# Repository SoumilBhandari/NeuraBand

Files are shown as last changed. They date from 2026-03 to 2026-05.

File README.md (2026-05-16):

<div align="center">

<h1>NeuraBand</h1>

<p><b>A wearable biomarker monitor built to help slow the progression of Alzheimer's disease</b></p>

<p>
NeuraBand is a pill-sized wearable that continuously and passively tracks <b>ten</b> neurologically
relevant biomarkers, then streams them live over Bluetooth Low Energy to a clinical-grade
dashboard and a patient-facing mobile app. Its purpose is not simply to detect Alzheimer's
disease — it is to <b>slow the disease's progression</b>, by surfacing the earliest warning signs
while there is still time for intervention to change its course.
</p>

<p>






</p>

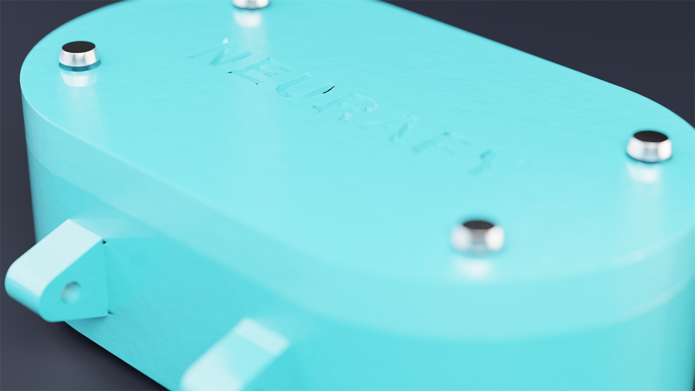
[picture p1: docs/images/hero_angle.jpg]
NeuraBand wearable device — angled render


</div>

---

<p align="center">
<a href="#why-it-matters">Why It Matters</a> &nbsp;·&nbsp;
<a href="#how-it-works">How It Works</a> &nbsp;·&nbsp;
<a href="#the-ten-modalities">Modalities</a> &nbsp;·&nbsp;
<a href="#the-device">The Device</a> &nbsp;·&nbsp;
<a href="#whats-in-this-repo">Components</a> &nbsp;·&nbsp;
<a href="#quick-start">Quick Start</a> &nbsp;·&nbsp;
<a href="#bill-of-materials">BOM</a> &nbsp;·&nbsp;
<a href="#ble-protocol">BLE Protocol</a> &nbsp;·&nbsp;
<a href="#scientific-basis">Science</a>
</p>

---

## Why It Matters

Alzheimer's disease begins damaging the brain **years before memory symptoms appear** — and
some of the earliest regions affected are those that govern *autonomic* functions: heart-rhythm
regulation, skin conductance, and motor coordination. Today those changes are usually caught
only at an annual clinic visit, if at all.

NeuraBand takes the opposite approach: **continuous, passive monitoring**. By wearing one
unobtrusive band, a subject contributes a 24/7 stream of prodromal biomarkers — the kind of
longitudinal signal that periodic assessments simply cannot capture.

Detection, though, is only the first step. The early window NeuraBand opens is also the
**treatable** window — the sooner decline is caught, the sooner lifestyle changes, medication,
and clinical care can begin. Earlier, better-informed intervention is what gives a person the
best chance of **slowing how fast Alzheimer's progresses**, and that is the outcome NeuraBand
is built for.

Four of the ten tracked modalities are *primary* AD biomarkers, each chosen for a documented
link to neurodegeneration:

| Biomarker | Sensor | Why it is relevant to Alzheimer's |
|---|---|---|
| **Heart-rate variability** | MAX30102 PPG | Low HRV reflects autonomic dysfunction; the lowest-HRV / highest blood-pressure-variability quartile carries a **2.34× ADRD risk** *(Rouch et al., 2024)*. |
| **Blood oxygen (SpO₂)** | MAX30102 pulse oximetry | Reduced peripheral SpO₂ is associated with cognitive impairment and sleep-disordered breathing. |
| **Electrodermal activity** | Grove GSR + built-in electrodes | EDA is governed by the ventromedial frontal cortex and anterior cingulate — regions hit early in AD pathology. |
| **Gait variability** | BMI270 IMU | The **strongest evidence base**: wearable-IMU gait analysis differentiates dementia subtypes, and ML on gait data reaches **85.5% accuracy** detecting mild cognitive impairment. |

> No single biomarker is diagnostic. NeuraBand's value is in **fusing many weak signals** into one
> longitudinal picture — see the [Scientific Basis](#scientific-basis) section for 13
> peer-reviewed studies behind these choices.

---

## How It Works

Six sensors feed an Arduino Nano 33 BLE Sense Rev2. On-device firmware fuses them into ten
modality streams plus a composite **Neuro-Risk Index**, packages everything as a compact JSON
frame once per second, and notifies any connected Bluetooth client.

```
   SENSORS                         DEVICE                              CLIENTS

 MAX30102  --+                                                  +-->  Web Dashboard
 Grove GSR --+                                                  |     Web Bluetooth / Chrome
 BMI270    --+--> Arduino Nano 33 BLE Sense Rev2  --BLE 5.0 -----+
 HS3003    --+      nRF52840 SoC                                 |
 APDS9960  --+      10-modality fusion + Neuro-Risk Index        +-->  Mobile App
 LPS22HB   --+      JSON telemetry @ 1 Hz                              React Native / Expo
```

The device exposes one custom 128-bit GATT service over Bluetooth Low Energy. Any Web Bluetooth
browser or the React Native app can connect to it directly — no pairing dance, no cloud account,
no companion dongle.

---

## The Ten Modalities

The Nano 33 BLE Sense carries an IMU and environmental sensors on-board, so a single external
PPG breakout and a GSR module are enough to surface **ten** continuous streams:

| # | Modality | Sensor | What it captures |
|:-:|---|---|---|
| 1 | Heart-rate variability | MAX30102 PPG | SDNN / RMSSD / IBI — autonomic regulation |
| 2 | Blood oxygen (SpO₂) | MAX30102 | Peripheral oxygenation |
| 3 | Electrodermal activity | Grove GSR + SS electrodes | Sympathetic / stress response |
| 4 | Gait variability | BMI270 IMU | Activity level and motor patterns |
| 5 | Respiratory rate | MAX30102 (PPG envelope) | Breathing extracted from sinus arrhythmia |
| 6 | Skin temperature | HS3003 | Circadian-rhythm tracking |
| 7 | Sleep quality | BMI270 actigraphy | Cole–Kripke sleep/wake estimation |
| 8 | Skin humidity | HS3003 | Sweat / sympathetic response |
| 9 | Ambient light | APDS9960 | Circadian light exposure |
| 10 | Barometric pressure | LPS22HB | Altitude / floor-change detection |
| ★ | **Neuro-Risk Index** | *computed* | Weighted fusion of every stream into a 0–100 score |

---

## The Device

A 70 × 42 × 21 mm pill-shaped enclosure, 3D-printed in PLA, that mounts to any standard 24 mm
quick-release watch band. The skin-facing surface integrates the optical PPG window and two
stainless-steel GSR electrodes; the side carries a USB-C charging port and a power switch.

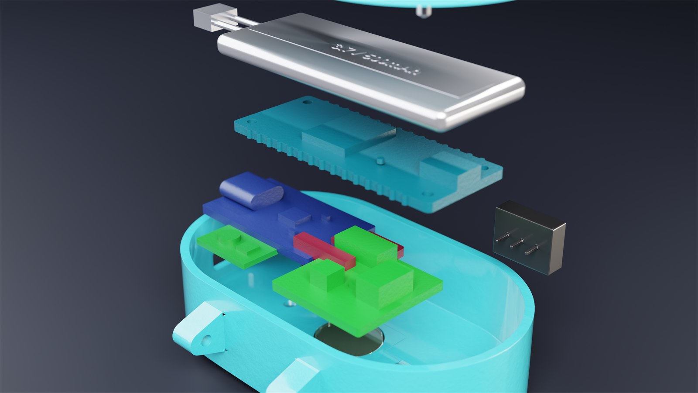
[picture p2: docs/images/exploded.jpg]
Exploded view of the NeuraBand assembly


<table>
<tr>
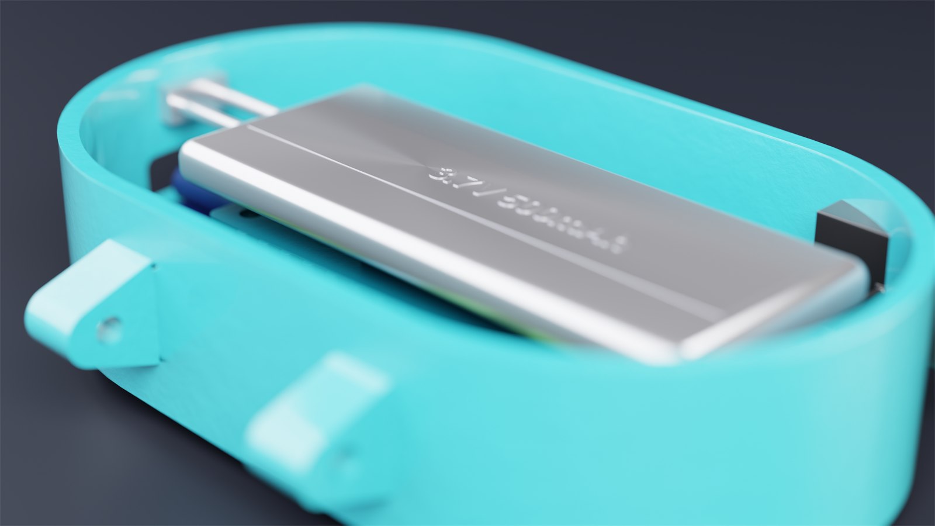
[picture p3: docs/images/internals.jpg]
Internal layout
<td width="50%"></td>
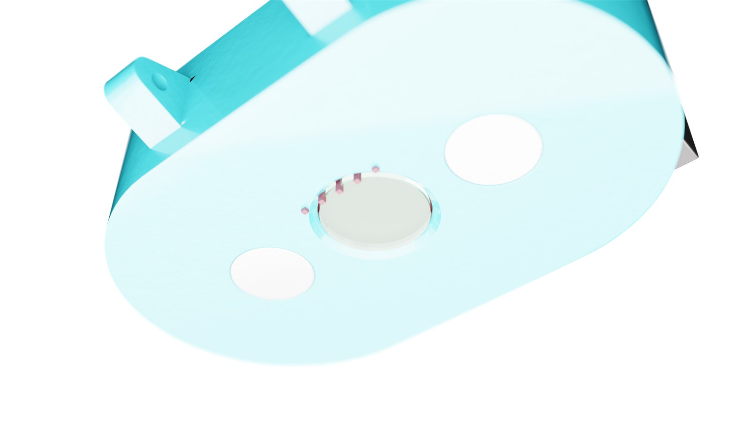
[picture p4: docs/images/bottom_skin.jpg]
Skin-contact surface with PPG window and electrodes
<td width="50%"></td>
</tr>
<tr>
<td align="center"><sub>500 mAh LiPo seated above the Arduino</sub></td>
<td align="center"><sub>Skin side — optical PPG window flanked by GSR electrodes</sub></td>
</tr>
<tr>
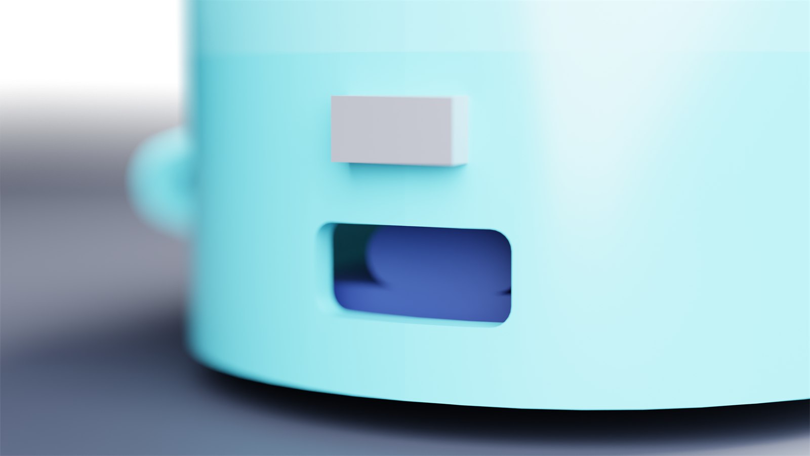
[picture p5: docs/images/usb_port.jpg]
USB-C charging port
<td width="50%"></td>
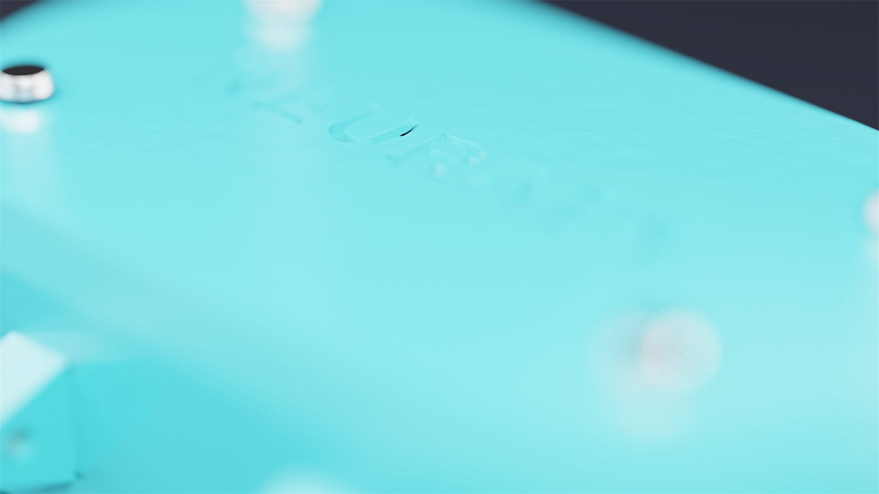
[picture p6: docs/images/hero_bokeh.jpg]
Enclosure detail
<td width="50%"></td>
</tr>
<tr>
<td align="center"><sub>USB-C charge port and power switch</sub></td>
<td align="center"><sub>Embossed shell — print-finished detail</sub></td>
</tr>
</table>

---

## What's in This Repo

NeuraBand is a full hardware-plus-software build. Every layer lives here:

### Firmware &nbsp;·&nbsp; `firmware/`

An 884-line Arduino sketch (`neuraband_firmware.ino`) that runs the whole device:

- **10-modality sensor fusion** with non-blocking `millis()` scheduling — MAX30102 at 50 Hz,
  GSR and IMU at 10 Hz, environmental sensors at 0.1 Hz, BLE transmit at 1 Hz.
- **On-device HRV** — SDNN computed from a rolling 60-sample inter-beat-interval buffer.
- **SpO₂** via a ratio-of-ratios method with an empirical MAX30102 calibration curve.
- **Respiratory rate** extracted from the PPG amplitude envelope (respiratory sinus arrhythmia).
- **Sleep actigraphy** — a simplified Cole–Kripke classifier over a 5-minute motion window.
- **Composite Neuro-Risk Index** — weighted multimodal fusion into a single 0–100 score.
- **Resilience built in** — software watchdog (resets on a >5 s loop stall), I²C bus
  auto-recovery, a BLE software-reset characteristic, and tri-color LED status indicators.

### Clinical Dashboard &nbsp;·&nbsp; `dashboard/`

A zero-install web app that connects straight to the device through the **Web Bluetooth API**.

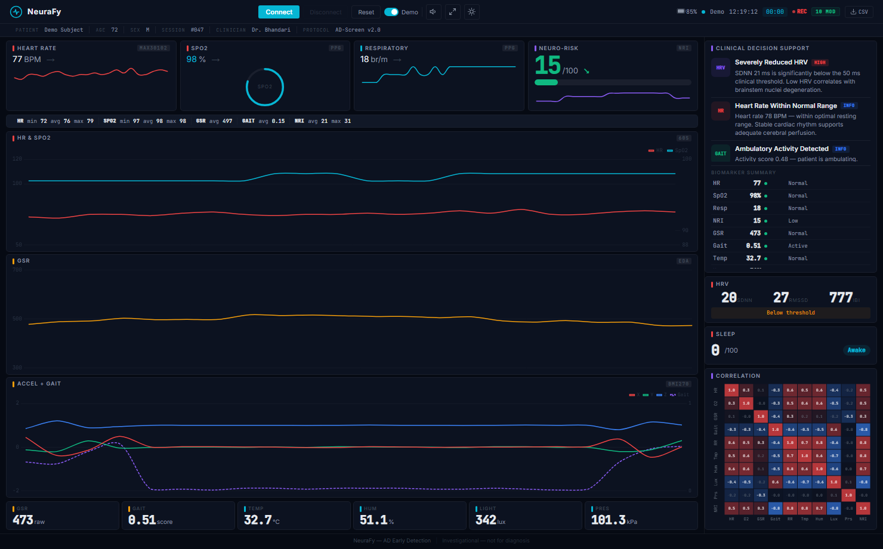
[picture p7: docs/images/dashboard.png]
NeuraBand clinical dashboard in demo mode


- Real-time Chart.js plots (HR & SpO₂, GSR, accelerometer + gait) on a 60-second rolling window.
- A **Clinical Decision Support** panel that turns evidence-based thresholds into plain-language
  insights, alongside a 10-modality biomarker summary table.
- Dedicated HRV (SDNN / RMSSD / IBI), SpO₂ ring, sleep, and cross-modality correlation panels.
- Dark / light themes, a session timer, CSV export for ML pipelines, auto-reconnect, and a
  **demo mode** that streams synthetic physiology so the dashboard works with no hardware.
- Ships as `index.html` + `app.js` + `style.css`, plus a single-file `neurafy_standalone.html`.

### Mobile App &nbsp;·&nbsp; `mobile/`

A patient-facing React Native companion (Expo SDK 54, React Native 0.81) — the friendly
counterpart to the clinician dashboard.

- Five tabs — **Vitals**, **Trends**, **Tips**, **Ask**, and **More** — behind a guided
  onboarding flow.
- Connects to the band over BLE with `react-native-ble-plx`; clinical terms are softened into
  everyday language (*Brain Health*, *Heart Calmness*, *Movement*).
- A daily wellness score, a wear-streak tracker, and a conversational **health assistant** that
  answers plain-language questions about the latest readings.
- System-driven dark / light theming, haptics, on-device persistence, and the same synthetic
  **demo mode** — the app is fully explorable without a physical device.

### Enclosure &nbsp;·&nbsp; `enclosure/`

- A fully **parametric OpenSCAD** model (`neuraband_case.scad`) — every component pocket,
  the optical window, electrode bores, lug tabs, and screw bosses are driven by named variables.
- Ready-to-print STL shells (`bottom_shell.stl`, `top_shell.stl`, `test_fit.stl`) plus a `stl/`
  library of component models for fit visualization.
- High-resolution product renders (`renders/`) generated by the included Blender script
  `render_neurafy.py`.

### Docs &nbsp;·&nbsp; `docs/`

The full [bill of materials](docs/bom.md), a [wiring diagram](docs/wiring_diagram.txt) with the
complete pin map and I²C address table, [13 scientific references](docs/scientific_references.md),
and a printable parts-list PDF.

---

## Quick Start

Every part of NeuraBand can be explored on its own — and the dashboard and app both have a demo
mode, so **you do not need to build the hardware to try the software**.

### 1 · Print the enclosure

Open the print-ready wrappers in OpenSCAD, or drop the STL files straight into your slicer.

| Setting | Value |
|---|---|
| Layer height | 0.15 mm |
| Walls | 4 perimeters |
| Infill | 40% gyroid |
| Material | PLA (210 °C / 60 °C) |
| Supports | Tree — lug tabs only |
| Brim | 5 mm |

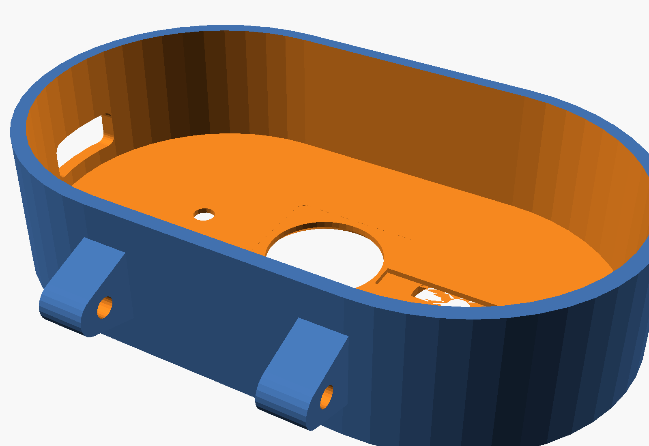
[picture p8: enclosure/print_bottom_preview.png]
Sliced bottom shell preview


### 2 · Flash the firmware

```bash
# Arduino IDE 2.x — install these from the Library Manager:
#   ArduinoBLE · Arduino_BMI270_BMM150 · Arduino_HS300x
#   Arduino_APDS9960 · Arduino_LPS22HB · SparkFun MAX3010x Sensor Library

# Board:  Arduino Nano 33 BLE
# Sketch: firmware/neuraband_firmware/neuraband_firmware.ino
# Connect the board over USB and upload (Ctrl/Cmd + U)
```

### 3 · Launch the dashboard

```bash
cd dashboard
python -m http.server 8000
# Open Chrome at http://localhost:8000
# Click "Connect" and pick "NeuraFy" (the device's Bluetooth name) — or flip "Demo" for no hardware.
```

> Web Bluetooth requires Chrome, Edge, or another Chromium browser over `http://localhost` or HTTPS.

### 4 · Run the mobile app

```bash
cd mobile
npm install
npx expo start
# Scan the QR code with Expo Go, or press  i / a  for an iOS / Android simulator.
```

The app opens in demo mode out of the box — no device or pairing required.

---

## Bill of Materials

The core electronics come in around **$55–65**; a complete build with band, fasteners, and
filament lands near **$75–85**.

| Component | Qty | Approx. cost | Notes |
|---|:---:|:---:|---|
| Arduino Nano 33 BLE Sense Rev2 | 1 | $35 | nRF52840, BMI270 IMU, BLE 5.0 |
| MAX30102 breakout (RCWL-0531) | 1 | $3–5 | Must be the 3.3 V I²C variant |
| Grove GSR sensor | 1 | $8–10 | Includes electrodes and cable |
| 500 mAh LiPo battery | 1 | $5–8 | Flat pouch with JST connector |
| TP4056 USB-C charging module | 1 | $2–3 | DW01A-protected (6-pin) version |
| MT3608 boost converter | 1 | $1–2 | Adjusted to 5.0 V output |
| Quick-release watch band (24 mm) | 1 | ~$5 | Standard spring-bar band |
| 3D-print filament, M2 screws, wiring, VHB tape | — | ~$10 | See full list |

> The complete, itemized list — including optional finishing supplies and required tools —
> is in [`docs/bom.md`](docs/bom.md).

---

## BLE Protocol

The device exposes one custom 128-bit GATT service. Sensor frames are pushed via notifications
once per second.

| Characteristic | UUID | Access | Purpose |
|---|---|---|---|
| Service | `19B10000-E8F2-537E-4F6C-D104768A1214` | — | GATT service container |
| Sensor Data | `19B10001-…` | Notify (1 Hz) | JSON sensor frame |
| Device Status | `19B10002-…` | Read | Firmware version + per-sensor health |
| Reset Command | `19B10003-…` | Write | Write `0x01` to reboot the device |

Each `Sensor Data` notification is a compact JSON object:

```json
{"hr":74,"sp":98,"gsr":487,"gait":0.42,"ibi":810,"ax":0.01,"ay":-0.99,"az":0.12,
 "rr":16,"tmp":32.4,"hum":48.0,"lux":220,"prs":101.3,"slp":82,"slps":0,"nri":21,
 "bt":85,"ts":42000}
```

| Key | Field | Key | Field |
|-----|---|-----|---|
| `hr` | Heart rate (BPM) | `tmp` | Skin temperature (°C) |
| `sp` | SpO₂ (%) | `hum` | Skin humidity (%) |
| `gsr` | Electrodermal activity (raw ADC) | `lux` | Ambient light (clear channel) |
| `gait` | Gait activity score | `prs` | Barometric pressure (kPa) |
| `ibi` | Inter-beat interval (ms) | `slp` | Sleep quality score (0–100) |
| `ax` `ay` `az` | Accelerometer (g) | `slps` | Sleeping flag (0 / 1) |
| `rr` | Respiratory rate (breaths/min) | `nri` | Neuro-Risk Index (0–100) |
| `bt` | Battery (%, −1 if unmonitored) | `ts` | Uptime (ms since boot) |

---

## Repository Layout

```
NeuraBand/
├── firmware/
│   └── neuraband_firmware/
│       └── neuraband_firmware.ino     Arduino firmware (884 lines)
├── dashboard/
│   ├── index.html · app.js · style.css   Web Bluetooth clinical dashboard
│   └── neurafy_standalone.html         Single-file build (no server needed)
├── mobile/
│   ├── App.js                          Entry point + tab navigation
│   └── src/
│       ├── screens/                    Vitals · Trends · Tips · Ask · Settings · Onboarding
│       ├── components/                 Reusable UI building blocks
│       ├── context/ · services/        BLE + synthetic-demo data providers
│       └── utils/                      HRV, threshold, and trend helpers
├── enclosure/
│   ├── neuraband_case.scad             Parametric OpenSCAD source
│   ├── print_*.scad · *.stl            Print-ready parts
│   ├── stl/ · renders/                 Component models + product renders
│   └── render_neurafy.py               Blender render script
├── docs/
│   ├── bom.md · wiring_diagram.txt     Build references
│   ├── scientific_references.md        13 peer-reviewed citations
│   └── images/                         README assets
└── README.md
```

---

## Scientific Basis

Each primary biomarker was selected from the peer-reviewed literature. Gait carries the
strongest evidence; HRV, SpO₂, and EDA are supporting signals whose power comes from being
combined rather than read in isolation.

<details>
<summary><b>13 peer-reviewed studies — click to expand</b></summary>

<br>

**Heart-rate variability**
1. da Silva VP et al. *Heart Rate Variability Indexes in Dementia: A Systematic Review.* Curr Alzheimer Res. 2018.
2. Choe YM et al. *HRV response to physical challenge predicts cognitive decline in MCI.* Front Aging Neurosci. 2022.
3. Rouch L et al. *Combined blood-pressure variability and HRV predict ADRD risk (HR 2.34).* Sci Rep. 2024.
4. Eyre B et al. *A critical perspective on HRV as an AD biomarker.* J Alzheimers Dis. 2026.

**Blood oxygen (SpO₂)**
5. *Peripheral oxygen saturation and cognitive impairment.* Sci Rep. 2025.
6. Bhatt S et al. *Sleep-disordered breathing, oxygenation coupling, and cognitive decline.* Sci Rep. 2024.

**Electrodermal activity**
7. Tranel D, Damasio H. *Neuroanatomical correlates of electrodermal responses.* Psychophysiology. 1994.
8. Tranel D. *Electrodermal activity in cognitive neuroscience.* Oxford Handbook of ERP Components. 2011.
9. van den Berg ME et al. *Electrodermal activity in dementia assessment.* Dement Geriatr Cogn Disord Extra. 2018.

**Gait analysis** *(strongest evidence)*
10. Mc Ardle R et al. *Wearable accelerometers differentiate dementia subtypes.* Gait Posture. 2020.
11. Soltani A et al. *ML ensemble achieves 85.5% MCI detection from IMU gait data.* Front Neurol. 2024.
12. Mc Ardle R et al. *Multi-centre study of gait changes in mild AD.* Alzheimers Res Ther. 2020.
13. *Wearable sensor system for early AD detection via multilevel gait assessment.* IEEE Access. 2023.

</details>

Full citations with DOIs and PMIDs are in [`docs/scientific_references.md`](docs/scientific_references.md).

---

## Limitations & Disclaimer

> [!IMPORTANT]
> **NeuraBand is a research prototype and a science-fair proof of concept — not a medical
> device.** It is not FDA-cleared, not clinically validated, and must not be used to diagnose,
> treat, or make decisions about any health condition.

- Consumer-grade sensors are far less accurate than clinical instruments; wrist PPG in
  particular is a weaker source for HRV than clinical ECG.
- The SpO₂ calibration curve is empirical and needs per-device tuning.
- GSR as a *preclinical* AD biomarker remains exploratory.
- Meaningful conclusions require longitudinal baselines — months or years of per-subject data.
- The Neuro-Risk Index is a demonstration of multimodal sensor fusion, **not** a diagnostic score.

---

## Credits

Built by **Soumil Bhandari** as a regional science-fair project — a wearable approach to
slowing Alzheimer's disease progression through continuous, passive biomarker monitoring.

Released under the [MIT License](LICENSE).

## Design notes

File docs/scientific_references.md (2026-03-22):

# NeuraBand — Scientific References

## Biomarker Justification for Alzheimer's Disease Research

### Heart Rate Variability (HRV) — MAX30102

1. **Autonomic dysfunction in dementia (systematic review)**
   HRV indexes show negative effect sizes across all types of dementia and MCI, indicating autonomic nervous system dysfunction.
   - da Silva VP et al. "Heart Rate Variability Indexes in Dementia: A Systematic Review with a Quantitative Analysis." *Curr Alzheimer Res.* 2018;15(1):80-88. PMID: 28558638

2. **HRV predicts cognitive decline in MCI**
   HRV response to physical challenge predicts cognitive decline in patients with mild cognitive impairment.
   - Choe YM et al. "Heart rate variability response to physical challenge predicts cognitive decline in MCI." *Front Aging Neurosci.* 2022;14:886023. doi: 10.3389/fnagi.2022.886023

3. **Combined BP variability and HRV predict ADRD risk**
   Patients in the highest quartile of blood pressure variability and lowest quartile of HRV had significantly increased ADRD risk (HR 2.34).
   - Rouch L et al. *Sci Rep.* 2024;14:3284. doi: 10.1038/s41598-024-52406-8

4. **Critical perspective on HRV as AD biomarker**
   Limited evidence for HRV as a predictor of cognitive and brain markers — "promising biomarker" label may be overly optimistic.
   - Eyre B et al. *J Alzheimers Dis.* 2026. doi: 10.1177/13872877251409343

### Blood Oxygen Saturation (SpO2) — MAX30102

5. **Peripheral oxygen saturation and cognitive impairment**
   Reduced peripheral SpO2 associated with cognitive impairments, particularly AD and vascular dementia.
   - PMC 2025. doi: 10.1038/s41598-025-87429-4

6. **Sleep-disordered breathing and cognitive decline**
   Brain-systemic oxygenation coupling during SDB events as a biomarker for MCI and cognitive decline.
   - Bhatt S et al. *Sci Rep.* 2024;14:28042. doi: 10.1038/s41598-024-84305-3

### Electrodermal Activity (EDA) — Grove GSR

7. **Neural basis of electrodermal activity**
   EDA controlled by ventromedial frontal cortex, anterior cingulate, and insula — regions overlapping with early AD pathology.
   - Tranel D, Damasio H. "Neuroanatomical correlates of electrodermal skin conductance responses." *Psychophysiology.* 1994;31(5):427-438.

8. **Electrodermal deficits in brain lesion patients**
   Patients with discrete lesions in ventromedial frontal and anterior cingulate regions show defective EDA responses.
   - Tranel D. "Electrodermal activity in cognitive neuroscience." In: *The Oxford Handbook of Event-Related Potential Components.* 2011.

9. **GSR in dementia assessment**
   Electrodermal activity used to measure emotional blunting and agitation in dementia patients.
   - van den Berg ME et al. *Dement Geriatr Cogn Disord Extra.* 2018;8(3):354-363. doi: 10.1159/000484890

### Gait Analysis — BMI270 IMU (Strongest Evidence)

10. **Wearable accelerometers differentiate dementia subtypes**
    Gait parameters (pace, variability, rhythm, asymmetry, postural control) from wearable accelerometers differentiated AD, Lewy body dementia, and Parkinson's disease.
    - Mc Ardle R et al. *Gait Posture.* 2020;76:265-270. doi: 10.1016/j.gaitpost.2019.12.023

11. **ML ensemble achieves 85.5% MCI detection from IMU gait data**
    Machine learning ensemble methods using wearable IMU gait data achieved 85.5% accuracy detecting MCI.
    - Soltani A et al. *Front Neurol.* 2024;15:1354092. doi: 10.3389/fneur.2024.1354092

12. **Multi-centre study: gait changes in mild AD**
    People with mild AD walk more slowly, more asymmetrically, with impaired variability and postural control compared to healthy controls.
    - Mc Ardle R et al. *Alzheimers Res Ther.* 2020;12(1):123. PMCID: PMC7617011

13. **Wearable sensor system for early AD detection**
    Early AD detection system using wearable sensors and multilevel gait assessment with machine learning ensemble approach.
    - IEEE Xplore, 2023. doi: 10.1109/ACCESS.2023.3256643

---

## How to Present to Judges

### Narrative Framework
1. Alzheimer's affects brain regions that control autonomic functions (heart rate regulation, skin conductance, motor coordination) **before** cognitive symptoms appear.
2. By monitoring these autonomic biomarkers continuously, we can potentially detect prodromal changes years earlier than current clinical assessments.
3. This wearable is a proof-of-concept that demonstrates real-time passive monitoring of four biomarkers with demonstrated links to neurodegeneration.

### Key Points to Emphasize
- **Gait analysis has the strongest evidence base** — cite references 10-13 when judges ask about scientific validity.
- **Multimodal approach** — no single biomarker is diagnostic; the value is in combining multiple streams.
- **Continuous passive monitoring** — unlike clinical assessments done once per year, this captures data 24/7.
- **Future pipeline integration** — this data could feed the same ML model that processes MRI and PET data.

### Limitations to Acknowledge (proactively)
- This is a research prototype, not a medical device.
- Consumer-grade sensors have lower accuracy than clinical instruments.
- Wrist-based PPG is less reliable than clinical ECG for HRV.
- GSR research in preclinical AD is still exploratory.
- Individual biomarker changes are not specific to Alzheimer's — the multimodal approach adds specificity.
- Longitudinal baseline comparison (tracking changes over months/years) is needed for clinical value.

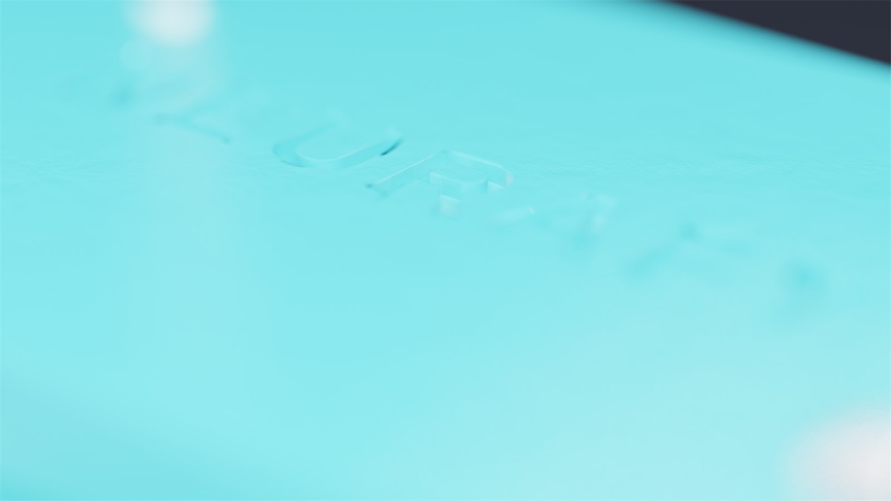
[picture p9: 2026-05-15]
docs/images/closeup_top.jpg

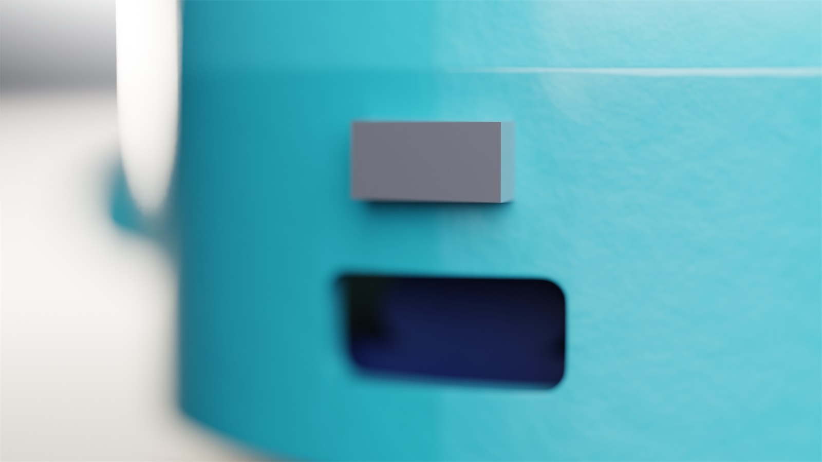
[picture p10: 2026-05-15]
docs/images/usb_side.jpg

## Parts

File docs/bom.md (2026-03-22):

# NeuraBand — Bill of Materials

## Core Components

| # | Component | Qty | Approx Cost | Source | Notes |
|---|---|-----|---|---|---|
| 1 | Arduino Nano 33 BLE Sense Rev2 | 1 | $35 | Arduino Store | nRF52840, BMI270 IMU, BLE 5.0 |
| 2 | MAX30102 Breakout (RCWL-0531) | 1 | $3-5 | Amazon | Must be 3.3V I2C compatible variant |
| 3 | Grove GSR Sensor | 1 | $8-10 | Seeed Studio | Includes finger electrodes and cable |
| 4 | 500mAh LiPo Battery | 1 | $5-8 | Amazon | Flat pouch, ~48x30x5mm, with JST connector |
| 5 | TP4056 USB-C Charging Module | 1 | $2-3 | Amazon | Must have DW01A protection (6-pin version) |
| 6 | MT3608 Boost Converter | 1 | $1-2 | Amazon | Adjustable output, set to 5.0V |

## Consumables & Accessories

| # | Item | Qty | Approx Cost | Notes |
|---|---|-----|---|---|
| 7 | Jumper Wires (female-female) | 10 | $3 | 10cm length preferred for tight enclosure |
| 8 | PLA Filament (white) | ~50g | $2 | From a standard 1kg spool |
| 9 | M2 x 5mm Self-Tapping Screws | 4 | $1 | Fallback if snap-fits break |
| 10 | 3M VHB Double-Sided Tape | 1 strip | $1 | For mounting components inside case |
| 11 | Silicone Watch Band (20mm) | 1 | $5 | Standard 20mm quick-release band |
| 12 | Heat Shrink Tubing | assorted | $2 | For wire insulation |

## Optional

| # | Item | Qty | Approx Cost | Notes |
|---|---|-----|---|---|
| 13 | 100k Resistors (1/4W) | 2 | $0.10 | For battery voltage divider on A1 |
| 14 | Sandpaper (400, 800, 1000 grit) | 1 each | $3 | Post-processing the enclosure |
| 15 | Rust-Oleum Filler Primer (gray) | 1 can | $6 | Smooths layer lines |
| 16 | Matte White Spray Paint | 1 can | $5 | Medical-grade white finish |

## Total Estimated Cost

- **Core components**: ~$55-65
- **With accessories**: ~$75-85
- **With optional finishing**: ~$90-95

## Tools Required (not purchased)

- Soldering iron + solder
- Multimeter (for MT3608 voltage adjustment)
- Small screwdriver (for GSR potentiometer calibration)
- Wire strippers
- Hot glue gun (for locking MT3608 potentiometer)
- Access to FDM 3D printer (0.4mm nozzle)

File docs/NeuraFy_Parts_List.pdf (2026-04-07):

# NeuraFy - Complete Parts List

## Wearable Biomarker Monitor for Early Alzheimer's Detection

# 1. Core Electronics

# | Product / Specification | Qty | Price | Where to Buy

1 | Arduino Nano 33 BLE Sense Rev2 [ABX00070]

nRF52840 SoC, BMI270 IMU, BLE 5.0, 45x18mm, 3.3V logic, with headers

| | 1 | $39.70 | store-usa.arduino.cc/products/nano-33-ble-sense-rev2-with-headers

2

### HiLetgo MAX30102 Heart Rate Sensor Breakout

Pulse oximetry + SpO2, I2C 3.3V, replaces MAX30100, 14x14mm PCB

1 | $5.99 | amazon.com/dp/B07QC67KMQ

3

### Seeed Studio Grove GSR Sensor v1.2

Galvanic skin response, 3.3V/5V, includes finger electrode straps + cable

1 | $7.90 | amazon.com/dp/B012TNYDE4 (or seeedstudio.com p-1614)

4

### EEMB 3.7V 500mAh LiPo Battery (403048)

Rechargeable Li-polymer, JST-PH 2.0 connector, 30.5x50x4.3mm pouch

1 | $9.99 | amazon.com/dp/B095W6742D

5

### HiLetgo TP4056 USB-C Charger Module (3-pack)

5V 1A Li-ion charger, DW01A + 8205A dual protection, Type-C input

1pk | $5.99 | amazon.com/dp/B07PKND8KG

6

### Pololu U3V16F3 3.3V Step-Up/Down Regulator

2.5-16V input, 3.3V 600mA output, 10x13mm, pin-compatible header

1 | $6.95 | pololu.com/product/4940

# 2. Enclosure & Mechanical

# | Product / Specification | Qty | Price | Where to Buy

7 | PLA Filament 1.75mm (white or teal)
| Any brand, 1kg spool (only ~50g needed), 200-220C print temp | 50g | $2 | amazon.com (Hatchbox, eSUN, Overture, etc.)

8

### uxcell M2x5mm Pan Head Self-Tapping Screws (50pk)

Phillips drive, 316 stainless steel, for case assembly (need 4 of 50)

4 | $6.49 | amazon.com/dp/B07Q36GBKY

9

### uxcell 10mm Stainless Steel Round Disc Blanks

3/8in dia, 1mm thick, 304 SS stamping blanks for GSR electrodes

2 | $6.49 | amazon.com/dp/B0FPLS43WW (100-pack, only need 2)

10

### MG Chemicals 8331-14G Silver Conductive Epoxy

Two-part silver-filled adhesive, bonds SS electrodes to signal wires

1 | $35 | amazon.com/dp/B07XYFJG7J

11

### Apple Watch 42mm/44mm/45mm Band Lug Adapters

Metal spring bar connectors, accepts 24mm straps, pair (black)

1pr | $8 | amazon.com/dp/B07M8PGJ9M

12

### 24mm Silicone/Nylon Quick-Release Watch Band

Breathable sport band, 24mm width, fits lug adapters above

| | 1 | $8 | amazon.com (search '24mm quick release watch band')

# 3. Wiring & Assembly

# | Product / Specification | Qty | Price | Where to Buy

13 | Female-to-Female Dupont Jumper Wires 10cm (40pk)
| 2.54mm pitch, 24AWG, multi-color, for internal wiring | 10+ | $4 | amazon.com/dp/B00RLQE3E0

14

### Ginsco 580pc Heat Shrink Tubing Kit

2:1 ratio, 6 colors, 11 sizes (1.5mm-10mm), polyolefin

1kit | $6.99 | amazon.com/dp/B01MFA3OFA

### NeuraFy Project - Page 1/3

## Wearable Biomarker Monitor for Early Alzheimer's Detection

15

### 3M VHB 4910 Double-Sided Mounting Tape

Clear, 1in wide, for securing battery + PCBs inside enclosure

1 ft | $1 | amazon.com (search '3M VHB tape clear 1 inch')

16

### 100k Ohm 1/4W Metal Film Resistors

For battery voltage divider on pin A1 (Vbat / 2)

| | 2 | $0.10 | amazon.com (any 100k 1/4W pack, e.g. dp/B0185FGYYA)

# 4. Optional Finishing (for science fair presentation)

# | Product / Specification | Qty | Price | Where to Buy

17 | Wet/Dry Sandpaper Assortment (400/800/1000 grit)
| For smoothing 3D printed layer lines before painting | 1set | $3 | amazon.com (search 'wet dry sandpaper assortment')

18

### Rust-Oleum Filler Primer Spray (gray)

Fills minor imperfections + layer lines, sand between coats

1can | $6 | amazon.com (search 'Rust-Oleum filler primer gray')

19

### Rust-Oleum 2X Matte Spray Paint (white or teal)

Final enclosure color coat, 2 light coats recommended

1can | $5 | amazon.com (search 'Rust-Oleum 2X matte spray')

# Cost Summary

Core electronics (items 1-6): | $76.52
Enclosure & mechanical (items 7-12): | $66.98
Wiring & assembly (items 13-16): | $12.09
Optional finishing (items 17-19): | $14.00
Total (without finishing): | $155.59
Total (with finishing): | $169.59

Note: Many parts come in multi-packs (screws 50pk, discs 100pk, wires 40pk).
Actual per-unit cost is lower. Prices as of April 2026, may vary.

# Tools Required (not purchased)

- Soldering iron + lead-free solder (e.g. Hakko FX-888D or any 60W station) - Multimeter (for setting Pololu output voltage, checking continuity) - Wire strippers / flush cutters - Small Phillips screwdriver (PH0 for M2 screws) - Hot glue gun (for locking regulator potentiometer after adjustment) - FDM 3D printer access (0.4mm nozzle, 0.2mm layer height, PLA at 210C)

# Quick Wiring Reference

## - LiPo BAT+ / BAT- to TP4056 B+ / B-- TP4056 OUT+ / OUT- to Pololu VIN / GND - Pololu VOUT (3.3V) to Arduino 3.3V pin (NOT VIN)

## Wearable Biomarker Monitor for Early Alzheimer's Detection

## - MAX30102 SDA/SCL to Arduino A4/A5 (I2C, 3.3V) - MAX30102 VIN to 3.3V, GND to GND - Grove GSR SIG to Arduino A0, VCC to 3.3V, GND to GND - SS Electrodes to Grove GSR finger electrode pads (via conductive silver epoxy) - Battery voltage divider: BAT+ to 100k to A1, A1 to 100k to GND

# Key Enclosure Specifications

- Enclosure dimensions: 70 x 42 x 21 mm (pill/capsule shape) - Wall thickness: 1.6 mm (structurally strong for PLA) - Screw holes: 4x M2 at corners (60mm x 32mm spacing) - USB-C port: left side cutout for TP4056 charging - Bottom skin-contact: 2x 10mm SS electrodes + 12.5mm optical sensor window - Band mounting: Apple Watch 42/44/45mm lug adapters (24mm strap width) - Internal Z-stack: floor 1.6mm, components 1.6-14.4mm, ceiling 16mm, top shell 5mm

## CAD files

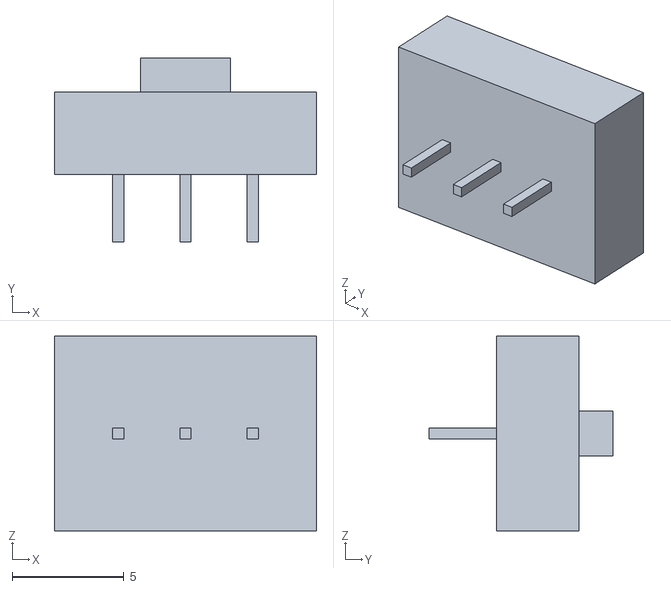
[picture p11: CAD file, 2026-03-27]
enclosure/stl/slide_switch.stl
11.7 x 8.20 x 8.70

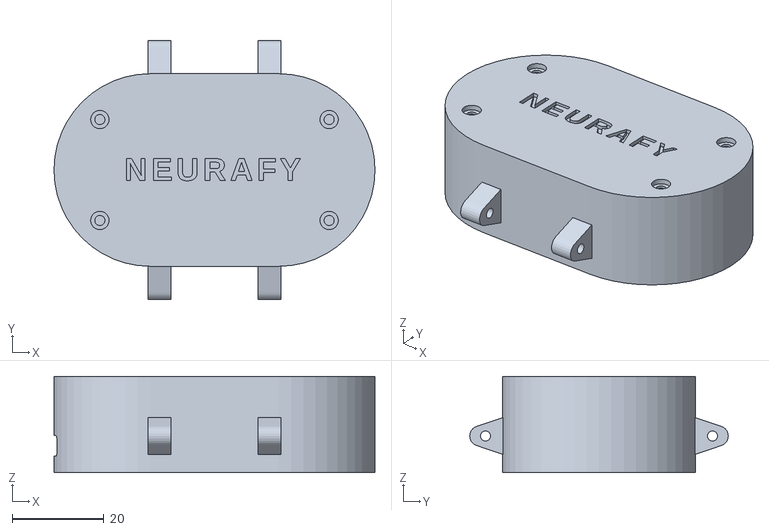
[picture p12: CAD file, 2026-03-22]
enclosure/test_fit.stl
70.0 x 56.4 x 21.0

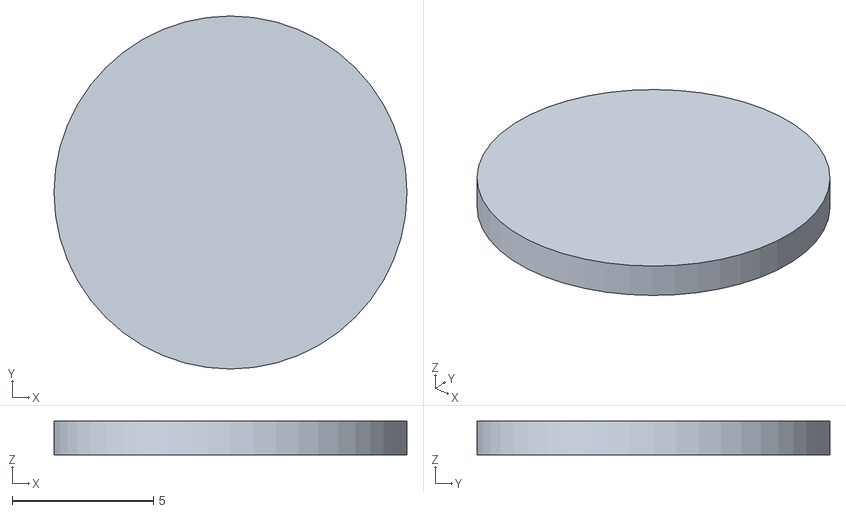
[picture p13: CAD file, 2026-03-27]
enclosure/stl/sensor_window.stl
12.5 x 12.5 x 1.20

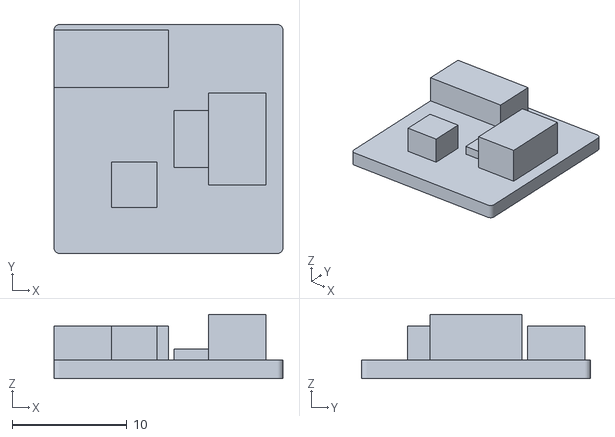
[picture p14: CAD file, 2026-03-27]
enclosure/stl/grove_gsr.stl
20.0 x 20.0 x 5.60

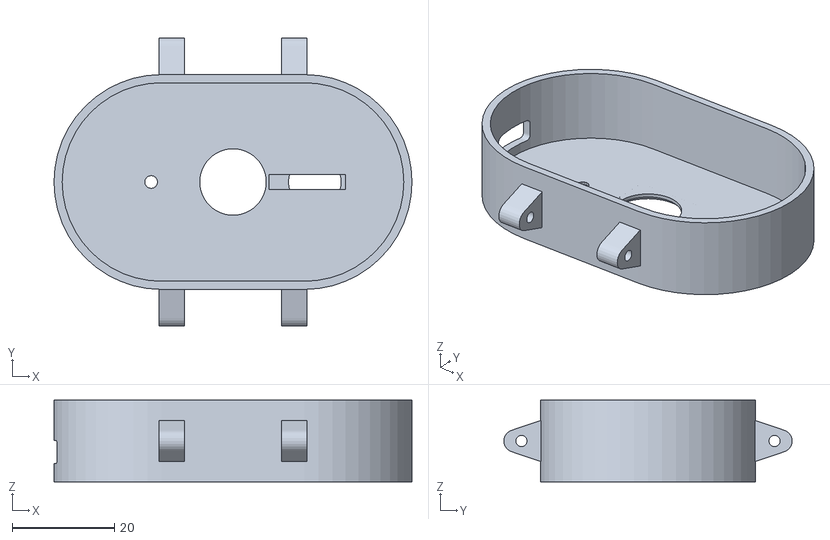
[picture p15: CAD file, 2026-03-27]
enclosure/stl/bottom_shell.stl
70.0 x 56.4 x 16.0

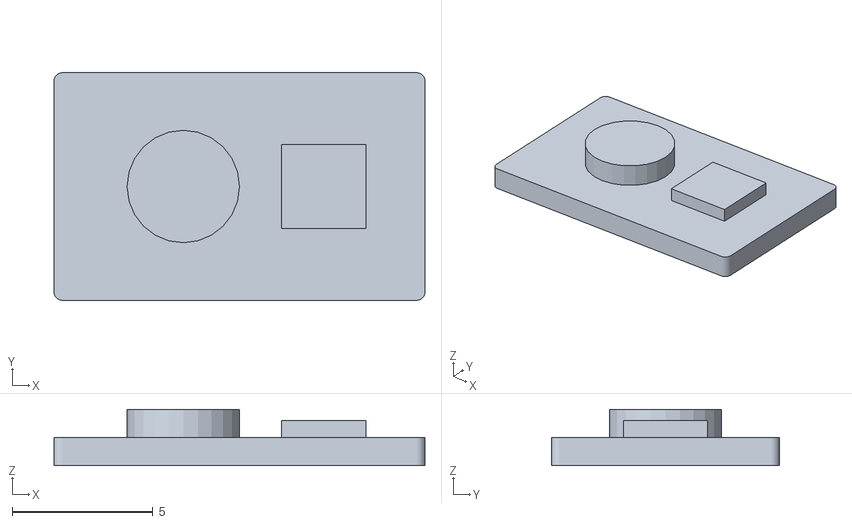
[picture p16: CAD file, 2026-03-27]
enclosure/stl/pololu.stl
13.2 x 8.10 x 2.00

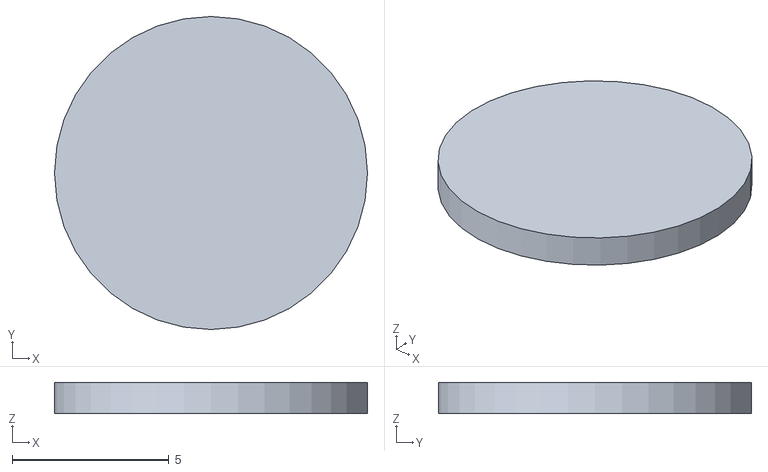
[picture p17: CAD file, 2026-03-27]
enclosure/stl/electrode_right.stl
10.0 x 10.0 x 1.00

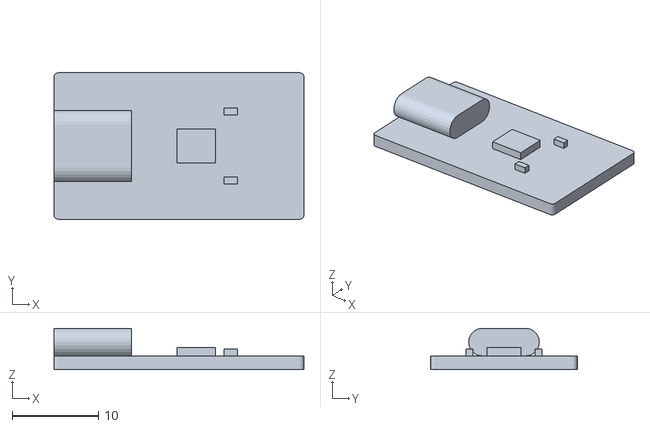
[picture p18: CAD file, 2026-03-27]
enclosure/stl/tp4056.stl
29.0 x 17.0 x 4.80

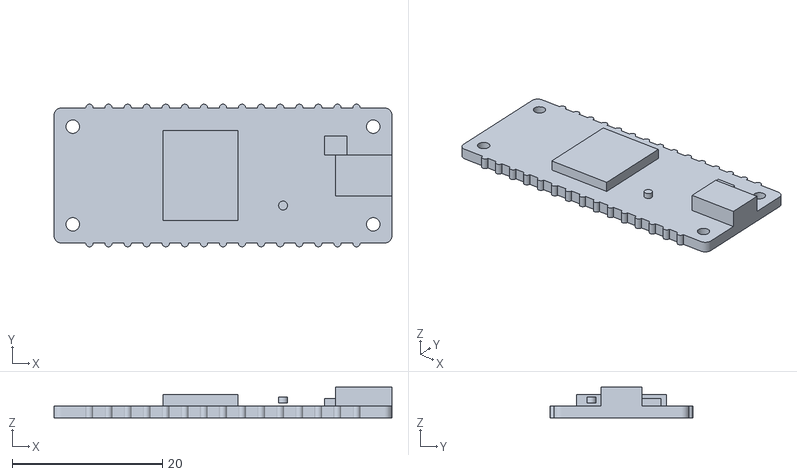
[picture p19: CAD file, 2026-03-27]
enclosure/stl/arduino.stl
45.0 x 19.0 x 4.10

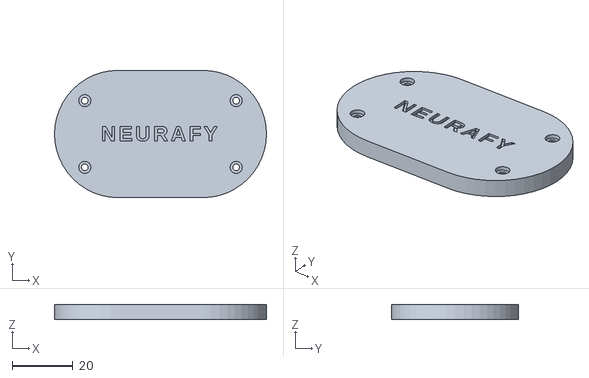
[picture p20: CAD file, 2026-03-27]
enclosure/stl/top_shell.stl
70.0 x 42.0 x 5.00

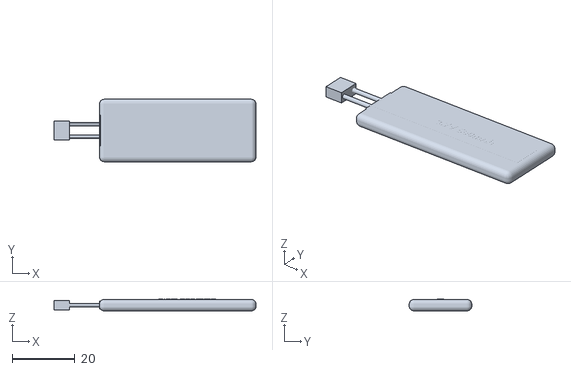
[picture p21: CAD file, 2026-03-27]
enclosure/stl/battery.stl
64.5 x 20.0 x 3.75

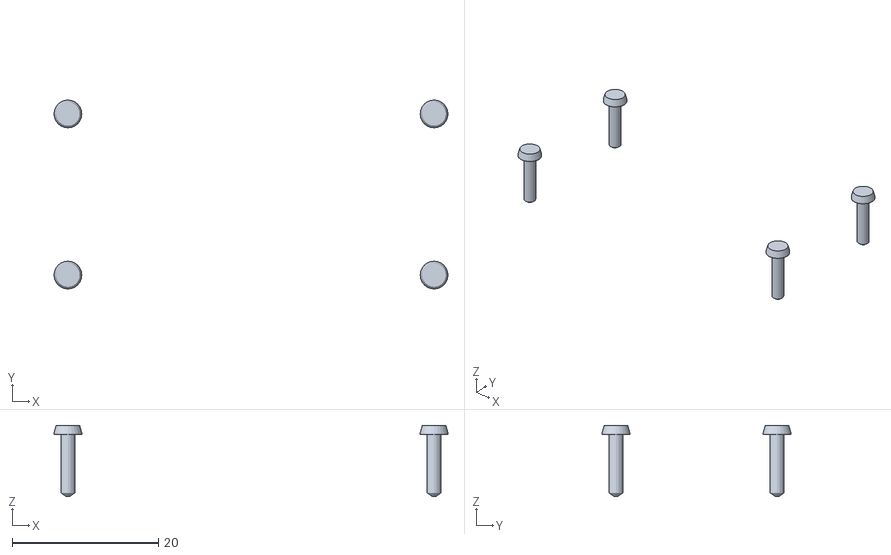
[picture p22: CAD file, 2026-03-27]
enclosure/stl/screws.stl
53.8 x 25.8 x 9.70

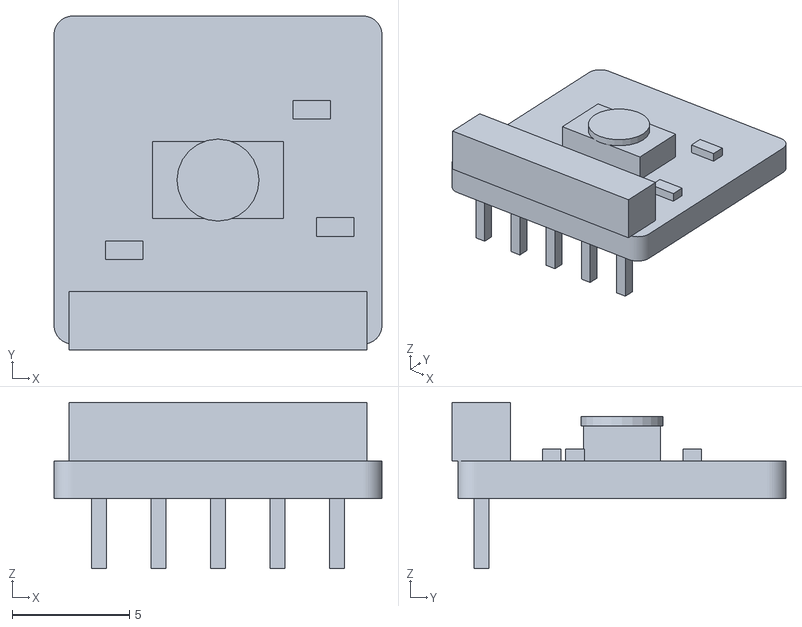
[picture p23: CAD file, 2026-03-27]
enclosure/stl/max30102.stl
14.0 x 14.2 x 7.10

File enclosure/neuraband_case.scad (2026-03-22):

/*
 * NeuraFy Enclosure v14 — All Collisions Fixed
 * ==============================================
 * Fixed 5 critical issues from v13 audit:
 *   1. USB-C port aligned with TP4056 connector (deeper cutout)
 *   2. Grove GSR moved inside pill boundary
 *   3. Battery centered on floor UNDER Arduino
 *   4. No TP4056↔Battery XY collision (different Z)
 *   5. No GSR↔Pololu collision (separated in Y)
 *
 * KEY INSIGHT: Battery on floor, Arduino ABOVE on 5.5mm standoffs.
 * All floor components share XY space with Arduino but at different Z.
 *
 * VERIFIED Z-STACK at center (X=3, Y=0):
 *   0.0mm   Skin contact
 *   1.6mm   Floor
 *   1.6mm   Floor components: TP4056(→5.9) Pololu(→4.1) GSR(→6.6) MAX30102(→5.1)
 *   6.6mm   Tallest floor component (GSR)
 *   ─── 0.5mm air gap ───
 *   7.1mm   Arduino PCB bottom (5.5mm standoffs)
 *   8.7mm   Arduino PCB top
 *  10.2mm   NINA BLE module top
 *   ─── 0.5mm air gap ───
 *  10.7mm   Battery bottom
 *  14.35mm  Battery top
 *  16.0mm   Bottom shell ceiling (1.65mm spare)
 *  21.0mm   Case exterior top
 *
 * VERIFIED PILL BOUNDARY (all components inside):
 *   TP4056 at X=-16: left edge -30.5, pill Y=10.2mm, width 17mm ✓
 *   Pololu at X=-16, Y=-12: at X=-16 pill Y=19.3mm, extends to -16 ✓
 *   GSR at X=10, Y=-8: right edge X=20, pill Y=18.45mm, extends to -18 ✓
 *   Battery at X=3: range [-22,28], fits within pill ✓
 *   Arduino at X=3: range [-19.5,25.5], fits within pill ✓
 *
 * COMPONENT DIMENSIONS (all verified against datasheets):
 *   Arduino Nano 33 BLE Rev2:  45 × 18 × 1.6mm
 *   MAX30102 breakout:         14 × 14 × 3.5mm
 *   TP4056 USB-C:              29 × 17 × 4.3mm
 *   Pololu U3V16F3:            13.2 × 8.1 × 2.54mm
 *   Grove GSR:                 20 × 20 × 5mm
 *   Battery:                   50 × 20 × 3.65mm
 *   Slide switch:              8.7 × 3.7 × 11.7mm
 *
 * PRINT SETTINGS:
 *   Layer: 0.15mm | Walls: 4 | Infill: 40% gyroid | Speed: 40mm/s
 *   Temp: 210/60C PLA | Supports: tree (lug tabs only) | Brim: 5mm
 */

// ═══════════ CASE DIMENSIONS ═══════════

case_l      = 70;
case_w      = 42;
case_h      = 21;    // was 18 — increased 3mm to fit battery above Arduino
wall        = 1.6;
corner_r    = case_w/2;   // 21mm → pill shape
bottom_h    = 16;    // was 13 — extra 3mm for battery layer
top_h       = case_h - bottom_h;  // 5
tol         = 0.20;
$fn         = 48;

// ═══════════ COMPONENTS (VERIFIED DIMENSIONS) ═══════════

// Arduino Nano 33 BLE Sense Rev2
nano_l      = 45;    nano_w = 18;    nano_h = 1.6;
nano_so_h   = 5.5;   // standoffs clear all floor components (tallest: GSR at 6.6mm)
nano_x      = 3;     // slightly right of center
nano_mx     = 20;    nano_my = 6.5;

// MAX30102 breakout (SQUARE)
max_pcb     = 14;    max_pcb_h = 3.5;
max_win_d   = 13;

// TP4056 USB-C charger
tp_l        = 29;    tp_w = 17;    tp_h = 4.3;
tp_x        = -16;   tp_y = 0;    // left side, USB-C connector faces -X wall

// Pololu U3V16F3 (user-verified: 0.32"×0.52"×0.1")
pol_l       = 13.2;  pol_w = 8.1;  pol_h = 2.54;
pol_x       = -16;   pol_y = -12;  // left side, below TP4056 in Y

// Grove GSR PCB
gsr_l       = 20;    gsr_w = 20;   gsr_h = 5;
gsr_x       = 10;    gsr_y = -8;   // right side, pill boundary verified

// LiPo Battery (ABOVE Arduino, not on floor — prevents floor collisions)
bat_l       = 50;    bat_w = 20;   bat_h = 3.65;
bat_x       = 3;     bat_y = 0;    // centered with Arduino
// Battery Z: sits above NINA module top (10.2mm) + 0.5mm gap = 10.7mm
// Battery top: 10.7 + 3.65 = 14.35mm. Ceiling at 16mm. 1.65mm spare ✓

// Slide switch (mounted sideways on wall)
sw_l        = 8.7;   sw_w = 3.7;   sw_h = 11.7;

// USB-C opening
usbc_w      = 10;    usbc_h = 4.5;

// GSR electrodes (solid stainless steel discs, 10mm dia × 1mm thick, no hole)
elec_d      = 10;    elec_depth = 1.0;    elec_sep = 16;

// ═══════════ SCREWS ═══════════
screw_boss_d = 5;    screw_hole_d = 1.7;    screw_inset = 10;

// ═══════════ LUG TABS ═══════════
lug_sep      = 24;   lug_tab_ext = 5;   lug_tab_w = 5;
lug_tab_h    = 8;    lug_bar_d   = 2.2;

// ═══════════ HELPERS ═══════════

module rrect(l, w, r) {
    cr = min(r, min(l, w)/2 - 0.01);
    if (cr <= 0) square([l, w], center=true);
    else hull() for (sx=[-1,1], sy=[-1,1])
        translate([sx*(l/2-cr), sy*(w/2-cr)])
        circle(r=cr, $fn=max(24, $fn));
}

module rbox(l, w, h, r) { linear_extrude(h) rrect(l, w, r); }

module standoff(d, h, hole_d) {
    difference() {
        cylinder(d=d, h=h);
        translate([0, 0, -0.1]) cylinder(d=hole_d, h=h+0.2);
    }
}

module rounded_box(l, w, h, r, fn=24) {
    hull() for (x=[-1,1], y=[-1,1], z=[-1,1])
        translate([x*(l/2-r), y*(w/2-r), z*(h/2-r)])
        sphere(r=r, $fn=fn);
}

module lug_tab() {
    embed = 2;
    difference() {
        hull() {
            translate([-embed/2, 0, 0])
                cube([embed, lug_tab_w, lug_tab_h], center=true);
            translate([lug_tab_ext, 0, 0])
                rotate([90, 0, 0])
                cylinder(d=lug_tab_h*0.55, h=lug_tab_w, center=true, $fn=24);
        }
        translate([lug_tab_ext*0.75, 0, 0])
            rotate([90, 0, 0])
            cylinder(d=lug_bar_d, h=lug_tab_w+4, center=true, $fn=24);
    }
}

// ═══════════ COMPONENT MODELS ═══════════
cfn = 24;

module arduino_nano_ble() {
    pcb_h = 1.6;
    // PCB
    color([0.0, 0.30, 0.35], 0.7)
    difference() {
        linear_extrude(pcb_h, center=true) rrect(nano_l, nano_w, 1);
        for (sx=[-1,1], sy=[-1,1])
            translate([sx*nano_mx, sy*nano_my, 0])
            cylinder(d=1.8, h=pcb_h+0.2, center=true, $fn=cfn);
    }
    // Castellated pads
    for (sy=[-1,1], i=[0:14]) {
        px = -(14/2*2.54) + i*2.54;
        color("Gold", 0.7) translate([px, sy*nano_w/2, 0])
            intersection() {
                cylinder(d=1.0, h=pcb_h, center=true, $fn=cfn);
                translate([0, sy*0.5, 0]) cube([1.2, 1.0, pcb_h+0.1], center=true);
            }
    }
    // Micro USB
    color([0.75, 0.75, 0.78], 0.7)
        translate([nano_l/2-3.75, 0, pcb_h/2+1.25]) cube([7.5, 5.5, 2.5], center=true);
    // NINA-B306
    color([0.08, 0.08, 0.08], 0.7)
        translate([-3, 0, pcb_h/2+0.75]) cube([10, 12, 1.5], center=true);
    // LED
    color([1, 0.5, 0], 0.7) translate([8, -4, pcb_h/2+0.4]) cylinder(d=1.2, h=0.8, $fn=cfn);
    // Reset
    color([0.7, 0.7, 0.72], 0.7) translate([15, 4, pcb_h/2+0.5]) cube([3, 2.5, 1.0], center=true);
}

module max30102_breakout() {
    pcb_h = 1.6;
    color([0.35, 0.08, 0.18], 0.7)
        linear_extrude(pcb_h, center=true) rrect(max_pcb, max_pcb, 0.8);
    color([0.06, 0.06, 0.06], 0.8)
        translate([0, 0, pcb_h/2+0.75]) cube([5.6, 3.3, 1.5], center=true);
    color([0.8, 0.85, 0.8], 0.3)
        translate([0, 0, pcb_h/2+1.5]) cylinder(d=3.5, h=0.4, $fn=cfn);
    for (pos=[[4,3],[-4,-3],[5,-2]])
        color([0.7, 0.6, 0.4], 0.6)
        translate([pos[0], pos[1], pcb_h/2+0.25]) cube([1.6, 0.8, 0.5], center=true);
    for (i=[0:4]) {
        px = -2*2.54+i*2.54;
        color("Gold", 0.6) translate([px, -max_pcb/2+1, -1.5])
            cube([0.64, 0.64, pcb_h+3], center=true);
    }
    color([0.15, 0.15, 0.15], 0.6)
        translate([0, -max_pcb/2+1, pcb_h/2+1.25]) cube([5*2.54, 2.5, 2.5], center=true);
}

module tp4056_charger() {
    pcb_h = 1.6;
    color([0.08, 0.15, 0.55], 0.7)
        linear_extrude(pcb_h, center=true) rrect(tp_l, tp_w, 0.5);
    // USB-C connector (on -X side of board)
    color([0.72, 0.72, 0.75], 0.8)
        translate([-tp_l/2+4.5, 0, pcb_h/2+1.6])
        hull() { for (sy=[-1,1]) translate([0, sy*2.5, 0])
            rotate([0, 90, 0]) cylinder(d=3.2, h=9, center=true, $fn=cfn); }
    // IC
    color([0.06, 0.06, 0.06], 0.7) translate([2, 0, pcb_h/2+0.5]) cube([4.5, 4, 1.0], center=true);
    // LEDs
    color([1, 0, 0], 0.7) translate([6, 4, pcb_h/2+0.4]) cube([1.6, 0.8, 0.8], center=true);
    color([0, 0.3, 1], 0.7) translate([6, -4, pcb_h/2+0.4]) cube([1.6, 0.8, 0.8], center=true);
}

module pololu_reg() {
    pcb_h = 1.0;
    color([0.08, 0.45, 0.15], 0.7)
        linear_extrude(pcb_h, center=true) rrect(pol_l, pol_w, 0.3);
    color([0.12, 0.12, 0.14], 0.8)
        translate([-2, 0, pcb_h/2+0.5]) cylinder(d=4, h=1.0, center=true, $fn=cfn);
    color([0.06, 0.06, 0.06], 0.7)
        translate([3, 0, pcb_h/2+0.3]) cube([3, 3, 0.6], center=true);
}
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

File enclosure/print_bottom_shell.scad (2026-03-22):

/*
 * NeuraFy — Bottom Shell (Print-Ready)
 * =====================================
 * Export: Render (F6) → Export as STL
 *
 * Orientation: Prints with floor DOWN (skin-contact side on build plate).
 *              This gives the smoothest finish on the sensor/electrode surface.
 *
 * PRINT SETTINGS:
 *   Layer height:  0.15mm
 *   Walls:         4 perimeters
 *   Infill:        40% gyroid
 *   Speed:         40mm/s
 *   Temp:          210°C nozzle / 60°C bed (PLA)
 *   Supports:      Tree supports (for lug tabs only)
 *   Brim:          5mm (helps adhesion on curved pill shape)
 *   Est. time:     ~2 hours
 *   Est. material: ~12g PLA
 *
 * DIMENSIONS: 70 × 42 × 16mm (pill shape)
 *
 * FEATURES:
 *   - MAX30102 sensor window (13mm dia, centered on bottom)
 *   - 2× GSR electrode recesses (10mm dia, 1mm deep, at ±16mm from center)
 *   - Wire channels through floor for electrode connections
 *   - USB-C port opening (left end, 22mm deep)
 *   - Slide switch slot (right side wall)
 *   - 4× M2 screw bosses with pilot holes
 *   - 4× Arduino standoffs (5.5mm tall)
 *   - MAX30102 mounting ring + board pocket
 *   - 4× Apple Watch lug tabs (spring bar channels)
 *   - Charging indicator holes
 */

use <neuraband_case.scad>

bottom_shell();

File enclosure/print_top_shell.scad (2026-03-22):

/*
 * NeuraFy — Top Shell / Lid (Print-Ready)
 * ========================================
 * Export: Render (F6) → Export as STL
 *
 * Orientation: Prints with the OUTER face DOWN (NEURAFY text on build plate).
 *              The lid is already oriented correctly — flat outer surface
 *              on the bottom, nesting lip pointing UP during print.
 *
 * PRINT SETTINGS:
 *   Layer height:  0.15mm
 *   Walls:         4 perimeters
 *   Infill:        40% gyroid
 *   Speed:         40mm/s
 *   Temp:          210°C nozzle / 60°C bed (PLA)
 *   Supports:      Light supports under battery retention rails
 *   Brim:          5mm
 *   Est. time:     ~45 minutes
 *   Est. material: ~8g PLA
 *
 * DIMENSIONS: 70 × 42 × 5mm (pill shape) + 3mm nesting lip
 *
 * FEATURES:
 *   - NEURAFY debossed text (0.8mm deep, clearly visible after print)
 *   - Nesting lip (3mm tall, fits inside bottom shell with 0.2mm tolerance)
 *   - Battery retention: Y-rails + X end stops + center rib
 *   - 4× M2 screw through-holes with countersinks
 */

use <neuraband_case.scad>

top_shell();

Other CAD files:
enclosure/stl/electrode_left.stl
enclosure/print_test_fit.scad
enclosure/bottom_shell.stl
enclosure/top_shell.stl

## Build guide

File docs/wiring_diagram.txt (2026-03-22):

NeuraBand Wiring Diagram
========================

POWER PATH
==========

    +-----------+          +----------+         +---------+
    |  USB-C    |          |  TP4056  |         | MT3608  |
    |  Power    |--5V----> | IN+  B+ |---+---> |VIN  VOUT|--> Arduino VIN (5V)
    |  Source   |--GND---> | IN-  B- |---+---> |GND  GND |--> Arduino GND
    +-----------+          +----------+   |     +---------+
                                          |
                                  +-------+-------+
                                  |   500mAh LiPo |
                                  |   3.7V        |
                                  |   (with JST)  |
                                  +---------------+

    IMPORTANT:
    - TP4056 B+/B- go to battery terminals
    - TP4056 OUT+/OUT- go to MT3608 VIN+/GND
    - MT3608 must be adjusted to 5.0V output BEFORE connecting to Arduino
    - Lock the MT3608 potentiometer with hot glue after adjustment

SENSOR CONNECTIONS
==================

                         ARDUINO NANO 33 BLE SENSE REV2
                         (Top View, USB port at top)

                          +--[USB Micro-B]--+
              5V from --> |VIN          D13| --> LED_BUILTIN (green)
         boost converter  |GND          D12|
                          |RST          D11|
                          |3V3          D10|
     Grove GSR SIG -----> |A0           D9 |
     (Battery V-div) ---> |A1           D8 |
                          |A2           D7 |
                          |A3           D6 |
     MAX30102 SDA ------> |A4 (SDA)     D5 |
     MAX30102 SCL ------> |A5 (SCL)     D4 |
                          |A6           D3 |
                          |A7           D2 |
                          +----------------+

MAX30102 BREAKOUT (RCWL-0531)        GROVE GSR SENSOR
+------------+                       +------------------+
| VIN <---------- Arduino 3V3       | VCC (Red) <---------- Arduino 3V3
| GND <---------- Common GND        | GND (Black) <-------- Common GND
| SDA ---------> Arduino A4         | NC  (White)  unused
| SCL ---------> Arduino A5         | SIG (Yellow) -------> Arduino A0
| INT   unused                      +------------------+
+------------+                       |
                                     | Finger electrodes
                                     | connect to module
                                     | via included cable

OPTIONAL BATTERY VOLTAGE DIVIDER (on A1)
=========================================

    Battery +  ----[100k]----+----[100k]---- GND
                             |
                             +-----------> Arduino A1

    This divides battery voltage by 2, so 4.2V reads as 2.1V
    (within the 3.3V ADC range). If not installed, firmware
    reports battery as -1.

COMPLETE CONNECTION SUMMARY
===========================

    +---+--------+------------------+------------------+
    | # | Arduino| Connected To     | Wire Color       |
    +---+--------+------------------+------------------+
    | 1 | VIN    | MT3608 VOUT+     | Red              |
    | 2 | GND    | Common Ground    | Black            |
    | 3 | 3V3    | MAX30102 VIN     | Orange           |
    | 4 | 3V3    | Grove GSR VCC    | Orange           |
    | 5 | A0     | Grove GSR SIG    | Yellow/Green     |
    | 6 | A1     | Battery V-divider| White (optional) |
    | 7 | A4/SDA | MAX30102 SDA     | Blue             |
    | 8 | A5/SCL | MAX30102 SCL     | Yellow           |
    +---+--------+------------------+------------------+

    Total external wires: 8 (6 required + 2 optional for battery monitor)

VOLTAGE LEVELS
==============

    - Arduino logic: 3.3V
    - MAX30102 I2C: 3.3V (no level shifting needed)
    - Grove GSR output: 0-3.3V (ratiometric to supply)
    - LiPo battery: 3.0V (empty) to 4.2V (full)
    - MT3608 output: 5.0V regulated
    - Arduino VIN input: 4.5V minimum required

I2C ADDRESS MAP
===============

    0x10 - BMM150  (onboard magnetometer)
    0x39 - APDS9960 (onboard light/gesture)
    0x44 - HS3003  (onboard temp/humidity)
    0x57 - MAX30102 (external HR/SpO2)  <-- our sensor
    0x5C - LPS22HB (onboard pressure)
    0x68 - BMI270  (onboard IMU)

    No address conflicts.

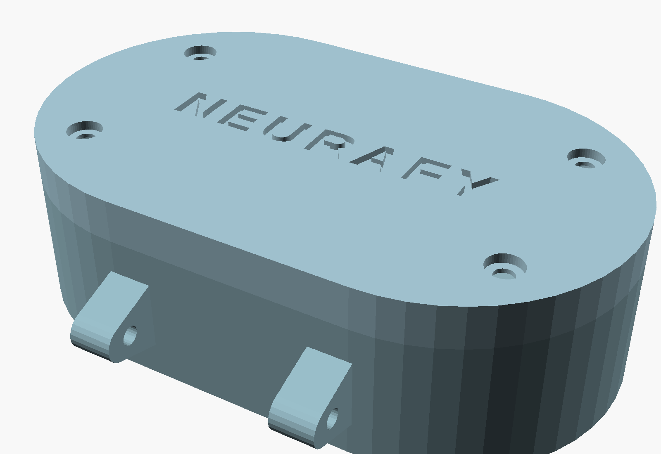
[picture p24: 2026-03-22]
enclosure/print_testfit_preview.png

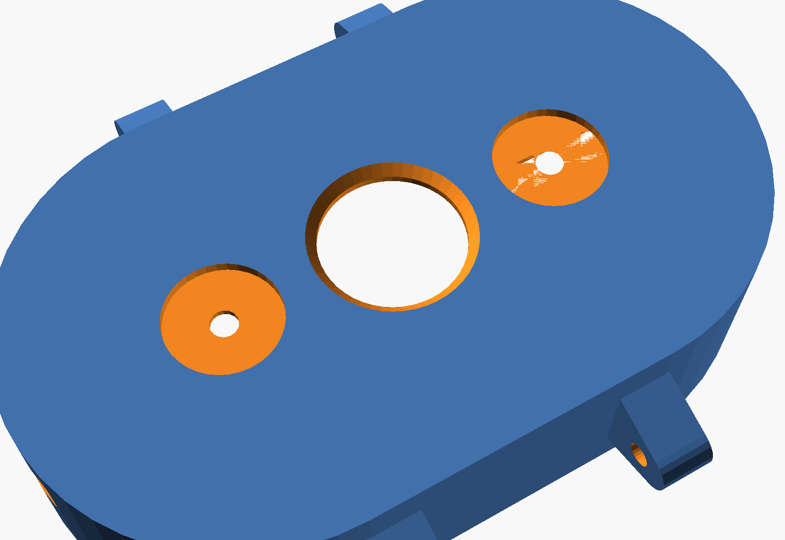
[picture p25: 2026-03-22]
enclosure/print_bottom_underside.png

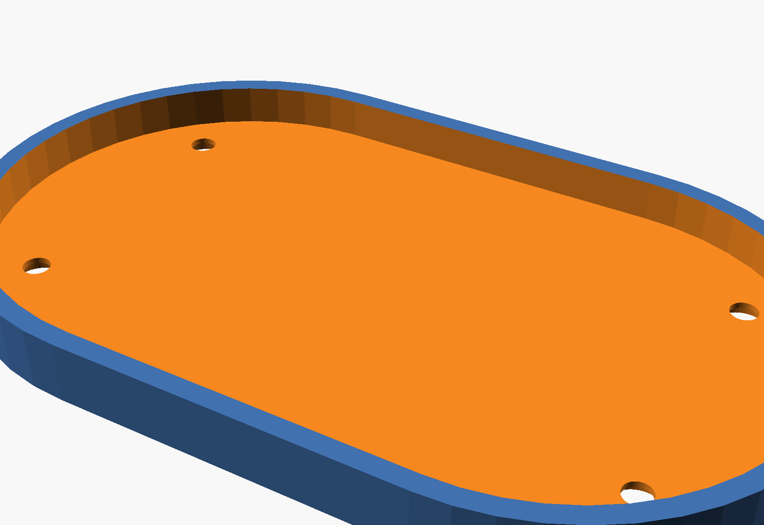
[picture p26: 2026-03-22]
enclosure/print_top_preview.png

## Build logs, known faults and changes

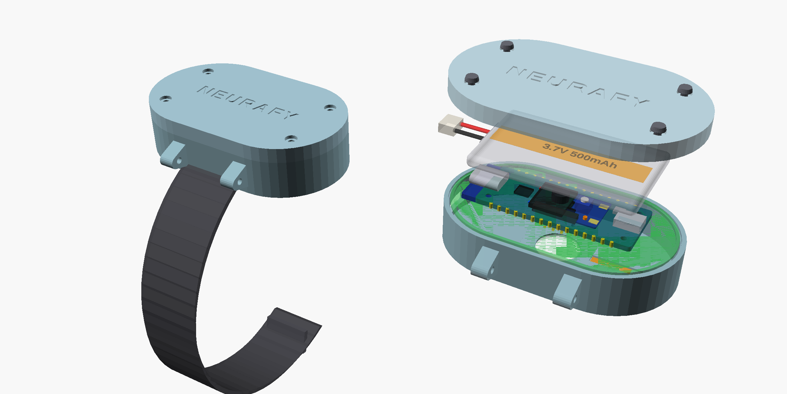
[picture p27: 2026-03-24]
enclosure/band_fix.png

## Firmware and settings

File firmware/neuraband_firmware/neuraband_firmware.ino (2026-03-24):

/*
 * NeuroWatch / NeuraFy Firmware
 * ================================
 * Wearable biomarker monitoring device for Alzheimer's disease research.
 * Reads heart rate, SpO2, galvanic skin response, and accelerometer data,
 * then streams JSON over BLE to a Chrome Web Bluetooth dashboard.
 *
 * Hardware:
 *   - Arduino Nano 33 BLE Sense Rev2 (nRF52840, BMI270 IMU onboard)
 *   - MAX30102 heart rate / SpO2 sensor on I2C (address 0x57)
 *   - Grove GSR PCB on A0, wired to built-in SS disc electrodes on case bottom
 *   - 500mAh LiPo → TP4056 USB-C charger → Pololu U3V16F3 (3.3V) → Arduino 3.3V pin
 *   - External slide switch controls power (no firmware interaction)
 *
 * BLE Protocol:
 *   - Service UUID:          19B10000-E8F2-537E-4F6C-D104768A1214
 *   - Sensor Data (Notify):  19B10001-E8F2-537E-4F6C-D104768A1214
 *   - Device Status (Read):  19B10002-E8F2-537E-4F6C-D104768A1214
 *   - Reset Command (Write): 19B10003-E8F2-537E-4F6C-D104768A1214 (write 0x01 to reboot)
 *
 * Modalities (7 biomarker streams):
 *   1. Heart rate + HRV (MAX30102 PPG)
 *   2. Blood oxygen SpO2 (MAX30102 pulse oximetry)
 *   3. Electrodermal activity (Grove GSR + built-in electrodes)
 *   4. Gait variability (BMI270 IMU accelerometer)
 *   5. Respiratory rate (extracted from PPG waveform envelope)
 *   6. Skin temperature (HS3003 onboard sensor, circadian rhythm tracking)
 *   7. Sleep quality (BMI270 actigraphy, Cole-Kripke algorithm)
 *   8. Skin humidity (HS3003, sympathetic sweat response)
 *   9. Ambient light (APDS9960, circadian light exposure tracking)
 *  10. Barometric pressure (LPS22HB, altitude/floor detection)
 *   + Composite Neuro-Risk Index (weighted fusion of all streams)
 *
 * JSON format (sent every 1 second):
 *   {"hr":72,"sp":98,"gsr":487,"gait":0.42,"ibi":832,"rr":16,"tmp":32.4,"slp":0,"slps":0,"nri":34,"bt":85,"ts":12345}
 *
 * LED Indicators:
 *   - Green (LED_BUILTIN or D13): BLE central connected
 *   - Blue (LEDB):                Transmitting data
 *   - Red (LEDR):                 Sensor error
 *
 * Author: NeuraFy Science Fair Project
 * License: MIT
 */

#include <ArduinoBLE.h>
#include <Wire.h>
#include <Arduino_BMI270_BMM150.h>
#include <Arduino_HS300x.h>    // Onboard HS3003 temperature/humidity sensor
#include <Arduino_APDS9960.h>  // Onboard APDS9960 light/proximity/color sensor
#include <Arduino_LPS22HB.h>   // Onboard LPS22HB barometric pressure sensor
#include "MAX30105.h"          // SparkFun MAX3010x library (works for MAX30102)
#include "heartRate.h"         // SparkFun beat detection algorithm

// ─────────────────────────────────────────────────────────────
// Pin Definitions
// ─────────────────────────────────────────────────────────────
static const int GSR_PIN       = A0;
static const int BATTERY_PIN   = A1;   // Voltage divider on TP4056 BAT output (before Pololu regulator)
                                       // Divider ratio may need calibration — default assumes 100k/100k (2:1)

// LED pins on Nano 33 BLE are active LOW
static const int LED_GREEN = LED_BUILTIN;  // D13
static const int LED_BLUE  = LEDB;
static const int LED_RED   = LEDR;

// ─────────────────────────────────────────────────────────────
// BLE UUIDs — custom 128-bit to avoid conflicts with BT SIG profiles
// ─────────────────────────────────────────────────────────────
static const char* SERVICE_UUID      = "19B10000-E8F2-537E-4F6C-D104768A1214";
static const char* SENSOR_DATA_UUID  = "19B10001-E8F2-537E-4F6C-D104768A1214";
static const char* DEVICE_STATUS_UUID = "19B10002-E8F2-537E-4F6C-D104768A1214";
static const char* RESET_CMD_UUID     = "19B10003-E8F2-537E-4F6C-D104768A1214";

// ─────────────────────────────────────────────────────────────
// BLE Objects
// ─────────────────────────────────────────────────────────────
BLEService neurafyService(SERVICE_UUID);

// 256 bytes max for the JSON payload — well within BLE MTU limits
BLEStringCharacteristic sensorDataChar(SENSOR_DATA_UUID,
                                        BLERead | BLENotify, 256);
BLEStringCharacteristic deviceStatusChar(DEVICE_STATUS_UUID,
                                          BLERead, 128);

// Reset command — write 0x01 to trigger NVIC_SystemReset()
BLEByteCharacteristic resetCmdChar(RESET_CMD_UUID, BLEWrite);

// ─────────────────────────────────────────────────────────────
// MAX30102 Sensor
// ─────────────────────────────────────────────────────────────
MAX30105 particleSensor;
bool max30102_ok = false;

// Beat detection state — SparkFun algorithm uses a rolling average
static const int RATE_SIZE = 8;   // Number of beats to average over
int16_t beatsPerMinute = 0;
int16_t beatAvg        = 0;
int32_t lastIBI        = 0;       // Inter-beat interval in ms
uint32_t lastBeatTime  = 0;

// SpO2 computation buffers
// We collect 100 samples (~2 seconds at 50Hz), then compute SpO2
static const int SPO2_BUFFER_SIZE = 100;
uint32_t irBuffer[SPO2_BUFFER_SIZE];
uint32_t redBuffer[SPO2_BUFFER_SIZE];
int spo2Value = -1;
bool spo2Valid = false;

// Rolling beat rate buffer for averaging
int16_t rates[RATE_SIZE];
uint8_t rateSpot = 0;

// IBI history for HRV (sent to dashboard for SDNN/RMSSD computation)
static const int IBI_HISTORY_SIZE = 60;
int32_t ibiHistory[IBI_HISTORY_SIZE];
uint8_t ibiIndex = 0;
uint8_t ibiCount = 0;

// ─────────────────────────────────────────────────────────────
// GSR Sensor
// ─────────────────────────────────────────────────────────────
static const int GSR_SAMPLES = 10;  // Average 10 reads to reduce noise
int gsrValue = 0;

// ─────────────────────────────────────────────────────────────
// BMI270 IMU — Gait Activity Score
// ─────────────────────────────────────────────────────────────
float accelX = 0.0f, accelY = 0.0f, accelZ = 0.0f;
float gyroX  = 0.0f, gyroY  = 0.0f, gyroZ  = 0.0f;

// Gait activity score: magnitude of acceleration deviation from 1g
// Higher values = more motion = walking/active
// Computed as exponential moving average of |accelMag - 1.0|
float gaitScore = 0.0f;
static const float GAIT_ALPHA = 0.1f;  // EMA smoothing factor

// ─────────────────────────────────────────────────────────────
// Respiratory Rate — extracted from MAX30102 IR signal envelope
// Breathing modulates PPG amplitude via respiratory sinus arrhythmia
// ─────────────────────────────────────────────────────────────
static const int RESP_BUF_SIZE = 500;  // 10 seconds at 50Hz
float respBuffer[RESP_BUF_SIZE];       // IR signal envelope
int respBufIdx = 0;
bool respBufFull = false;
int16_t respRate = -1;                 // breaths per minute

// ─────────────────────────────────────────────────────────────
// Skin Temperature — HS3003 onboard sensor (circadian tracking)
// ─────────────────────────────────────────────────────────────
bool hs300x_ok = false;
float skinTemp = -1.0f;
float skinHumidity = -1.0f;
float tempMin = 100.0f, tempMax = -40.0f;
uint32_t lastTempRead = 0;
static const uint32_t TEMP_INTERVAL = 10000;  // 10 seconds (slow-changing)

// ─────────────────────────────────────────────────────────────
// Ambient Light — APDS9960 onboard sensor (circadian tracking)
// ─────────────────────────────────────────────────────────────
bool apds_ok = false;
int ambientLight = -1;  // clear channel value (proxy for lux)

// ─────────────────────────────────────────────────────────────
// Barometric Pressure — LPS22HB onboard sensor (altitude/floor)
// ─────────────────────────────────────────────────────────────
bool baro_ok = false;
float baroPressure = -1.0f;  // kPa

// ─────────────────────────────────────────────────────────────
// Sleep Actigraphy — simplified Cole-Kripke from BMI270
// Classifies sleep/wake from 5-minute motion intensity window
// ─────────────────────────────────────────────────────────────
static const int SLEEP_BUF_SIZE = 300; // 5 minutes at 1Hz
float sleepBuffer[SLEEP_BUF_SIZE];
int sleepBufIdx = 0;
int sleepBufCount = 0;
int8_t sleepScore = -1;                // 0-100 quality
bool isSleeping = false;

// ─────────────────────────────────────────────────────────────
// Composite Neuro-Risk Index — weighted multimodal fusion
// Mirrors the science fair board's "probabilistic risk estimates"
// NOT diagnostic — demonstration of multimodal sensor fusion
// ─────────────────────────────────────────────────────────────
int8_t neuroRiskIndex = 0;

// ─────────────────────────────────────────────────────────────
// Timing — all non-blocking via millis()
// ─────────────────────────────────────────────────────────────
uint32_t lastMAX30102Read  = 0;
uint32_t lastGSRRead       = 0;
uint32_t lastIMURead       = 0;
uint32_t lastBLETransmit   = 0;
uint32_t lastLEDUpdate     = 0;
uint32_t loopStartTime     = 0;

static const uint32_t MAX30102_INTERVAL = 20;    // 50Hz for beat detection
static const uint32_t GSR_INTERVAL      = 100;   // 10Hz
static const uint32_t IMU_INTERVAL      = 100;   // 10Hz
static const uint32_t BLE_INTERVAL      = 1000;  // 1Hz JSON transmission
static const uint32_t LED_INTERVAL      = 500;   // LED blink rate
static const uint32_t WATCHDOG_TIMEOUT  = 5000;  // Reset if loop stalls >5s

// ─────────────────────────────────────────────────────────────
// Error tracking
// ─────────────────────────────────────────────────────────────
bool imu_ok = false;
uint8_t i2cErrorCount = 0;
static const uint8_t I2C_ERROR_THRESHOLD = 3;

// ─────────────────────────────────────────────────────────────
// Battery estimation
// ─────────────────────────────────────────────────────────────
// With a voltage divider (100k/100k) on A1, the ADC reads half of battery voltage.
// If no voltage divider is installed, battery reads as 0 and we report -1.
int batteryPercent = -1;

int estimateBattery() {
    int raw = analogRead(BATTERY_PIN);
    if (raw < 10) return -1;  // No voltage divider installed

    // ADC is 10-bit (0-1023), reference is 3.3V
    // With 100k/100k divider: Vbat = raw * 3.3 / 1023 * 2
    float voltage = raw * 3.3f / 1023.0f * 2.0f;

    // LiPo discharge curve approximation (3.0V = 0%, 4.2V = 100%)
    int percent = (int)((voltage - 3.0f) / 1.2f * 100.0f);
    if (percent < 0)   percent = 0;
    if (percent > 100)  percent = 100;
    return percent;
}

// ─────────────────────────────────────────────────────────────
// I2C Bus Recovery
// ─────────────────────────────────────────────────────────────
void recoverI2C() {
    Wire.end();
    delay(10);
    Wire.begin();
    i2cErrorCount = 0;
}

// ─────────────────────────────────────────────────────────────
// LED Helpers — Nano 33 BLE LEDs are active LOW
// ─────────────────────────────────────────────────────────────
void ledOn(int pin)  { digitalWrite(pin, LOW);  }
void ledOff(int pin) { digitalWrite(pin, HIGH); }

// ─────────────────────────────────────────────────────────────
// SETUP
// ─────────────────────────────────────────────────────────────
void setup() {
    Serial.begin(115200);
    // Don't block on Serial — device must work without USB connection
    uint32_t serialWait = millis();
    while (!Serial && (millis() - serialWait < 2000));

    Serial.println(F("NeuraFy Firmware v1.0"));
    Serial.println(F("========================"));

    // ── LED Setup ──
    pinMode(LED_GREEN, OUTPUT);
    pinMode(LED_BLUE,  OUTPUT);
    pinMode(LED_RED,   OUTPUT);
    ledOff(LED_GREEN);
    ledOff(LED_BLUE);
    ledOff(LED_RED);

    // ── I2C Setup ──
    Wire.begin();
    Wire.setClock(400000);  // 400kHz Fast Mode for responsive sensor reads

    // ── MAX30102 Initialization ──
    Serial.print(F("Initializing MAX30102... "));
    if (particleSensor.begin(Wire, I2C_SPEED_FAST)) {
        Serial.println(F("OK"));
        max30102_ok = true;

        // Configure for heart rate + SpO2 mode
        // Arguments: powerLevel, sampleAverage, ledMode, sampleRate, pulseWidth, adcRange
        //   powerLevel:   0x1F = 6.4mA (moderate power, good for wrist)
        //   sampleAverage: 4   (average 4 samples per FIFO slot)
        //   ledMode:       2   (Red + IR for SpO2)
        //   sampleRate:    400 (400 samples/sec before averaging = 100 effective Hz)
        //   pulseWidth:    411 (longest pulse = best resolution)
        //   adcRange:      4096 (full range)
        particleSensor.setup(0x1F, 4, 2, 400, 411, 4096);

        // Turn off the onboard MAX30102 temperature sensor to save a tiny bit of power
        particleSensor.enableDIETEMPRDY();
    } else {
        Serial.println(F("FAILED — check wiring and I2C address 0x57"));
        max30102_ok = false;
        ledOn(LED_RED);
    }

    // ── BMI270 IMU Initialization ──
    Serial.print(F("Initializing BMI270 IMU... "));
    if (IMU.begin()) {
        Serial.println(F("OK"));
        imu_ok = true;
        Serial.print(F("  Accelerometer sample rate: "));
        Serial.print(IMU.accelerationSampleRate());
        Serial.println(F(" Hz"));
    } else {
        Serial.println(F("FAILED — onboard IMU not responding"));
        imu_ok = false;
        ledOn(LED_RED);
    }

    // ── GSR Analog Pin ──
    pinMode(GSR_PIN, INPUT);
    Serial.println(F("GSR sensor on A0: OK"));

    // ── HS3003 Temperature Sensor ──
    Serial.print(F("Initializing HS3003 temp... "));
    if (HS300x.begin()) {
        Serial.println(F("OK"));
        hs300x_ok = true;
    } else {
        Serial.println(F("FAILED — onboard temp sensor not responding"));
        hs300x_ok = false;
    }

    // ── APDS9960 Light Sensor ──
    Serial.print(F("Initializing APDS9960 light... "));
    if (APDS.begin()) {
        Serial.println(F("OK"));
        apds_ok = true;
    } else {
        Serial.println(F("FAILED — onboard light sensor not responding"));
        apds_ok = false;
    }

    // ── LPS22HB Barometric Pressure ──
    Serial.print(F("Initializing LPS22HB pressure... "));
    if (BARO.begin()) {
        Serial.println(F("OK"));
        baro_ok = true;
    } else {
        Serial.println(F("FAILED — onboard pressure sensor not responding"));
        baro_ok = false;
    }

    // ── Battery Monitor ──
    pinMode(BATTERY_PIN, INPUT);

    // ── BLE Initialization ──
    Serial.print(F("Initializing BLE... "));
    if (!BLE.begin()) {
        Serial.println(F("FAILED — BLE hardware error"));
        ledOn(LED_RED);
        while (1);  // Can't proceed without BLE — halt
    }
    Serial.println(F("OK"));

    BLE.setLocalName("NeuraFy");
    BLE.setDeviceName("NeuraFy");
    BLE.setAdvertisedService(neurafyService);

    neurafyService.addCharacteristic(sensorDataChar);
    neurafyService.addCharacteristic(deviceStatusChar);
    neurafyService.addCharacteristic(resetCmdChar);
    BLE.addService(neurafyService);

    // Set initial status
    String statusJson = "{\"fw\":\"2.0\",\"max\":";
    statusJson += max30102_ok ? "1" : "0";
    statusJson += ",\"imu\":";
    statusJson += imu_ok ? "1" : "0";
    statusJson += ",\"tmp\":";
    statusJson += hs300x_ok ? "1" : "0";
    statusJson += ",\"lux\":";
    statusJson += apds_ok ? "1" : "0";
    statusJson += ",\"bar\":";
    statusJson += baro_ok ? "1" : "0";
    statusJson += ",\"gsr\":1,\"mod\":10}";  // 10 modalities
    deviceStatusChar.writeValue(statusJson);

    // Start advertising — 100ms interval balances discoverability and power
    BLE.setConnectionInterval(6, 12);  // 7.5ms - 15ms connection interval for low latency
    BLE.advertise();

    Serial.println(F("BLE advertising as 'NeuraFy'"));
    Serial.println(F("Waiting for connection..."));
    Serial.println();

    // Initialize beat detection arrays
    for (int i = 0; i < RATE_SIZE; i++) rates[i] = 0;
    for (int i = 0; i < IBI_HISTORY_SIZE; i++) ibiHistory[i] = 0;

    // Initialize new sensor buffers
    for (int i = 0; i < RESP_BUF_SIZE; i++) respBuffer[i] = 0;
    for (int i = 0; i < SLEEP_BUF_SIZE; i++) sleepBuffer[i] = 0;
}

// ─────────────────────────────────────────────────────────────
// READ MAX30102 — called at 50Hz for reliable beat detection
// ─────────────────────────────────────────────────────────────
void readMAX30102() {
    if (!max30102_ok) return;

    uint32_t irValue = particleSensor.getIR();

    // Finger detection: IR value > 50000 typically means finger is on sensor
    if (irValue < 50000) {
        beatsPerMinute = 0;
        beatAvg = 0;
        lastIBI = 0;
        return;
    }

    // Store IR value for respiratory rate extraction
    // Breathing modulates IR amplitude — low-frequency envelope gives resp rate
    respBuffer[respBufIdx] = (float)irValue;
    respBufIdx = (respBufIdx + 1) % RESP_BUF_SIZE;
    if (respBufIdx == 0) respBufFull = true;

    // Beat detection using SparkFun algorithm
    if (checkForBeat(irValue)) {
        uint32_t now = millis();
        int32_t delta = now - lastBeatTime;
        lastBeatTime = now;

        // Sanity check: IBI should be between 300ms (200 BPM) and 2000ms (30 BPM)
        if (delta > 300 && delta < 2000) {
            beatsPerMinute = 60000 / delta;
            lastIBI = delta;

            // Store IBI for HRV analysis
            ibiHistory[ibiIndex] = delta;
            ibiIndex = (ibiIndex + 1) % IBI_HISTORY_SIZE;
            if (ibiCount < IBI_HISTORY_SIZE) ibiCount++;

            // Rolling average of BPM
            rates[rateSpot++] = beatsPerMinute;
            rateSpot %= RATE_SIZE;

            int32_t sum = 0;
            for (int i = 0; i < RATE_SIZE; i++) sum += rates[i];
            beatAvg = sum / RATE_SIZE;
        }
    }
}
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
void loop() {
    loopStartTime = millis();

    // ── BLE event processing ──
    BLEDevice central = BLE.central();

    bool connected = (central && central.connected());
    uint32_t now = millis();

    // ── MAX30102 at 50Hz (every 20ms) ──
    if (now - lastMAX30102Read >= MAX30102_INTERVAL) {
        lastMAX30102Read = now;
        readMAX30102();
    }

    // ── GSR at 10Hz (every 100ms) ──
    if (now - lastGSRRead >= GSR_INTERVAL) {
        lastGSRRead = now;
        readGSR();
    }

    // ── IMU at 10Hz (every 100ms) ──
    if (now - lastIMURead >= IMU_INTERVAL) {
        lastIMURead = now;
        readIMU();
    }

    // ── Temperature + Humidity + Pressure at 0.1Hz (every 10 seconds) ──
    if (now - lastTempRead >= TEMP_INTERVAL) {
        lastTempRead = now;
        readTemperature();
        readBaroPressure();
    }

    // ── BLE Transmission at 1Hz (every 1000ms) ──
    if (now - lastBLETransmit >= BLE_INTERVAL) {
        lastBLETransmit = now;

        // Update SpO2 once per second (doesn't need 50Hz sampling)
        computeSpO2();

        // Update ambient light (1Hz — light doesn't change fast)
        readAmbientLight();

        // Update respiratory rate from PPG envelope
        computeRespRate();

        // Update sleep actigraphy
        updateSleepActigraphy();

        // Compute composite neuro-risk index
        computeNeuroRiskIndex();

        // Update battery level
        batteryPercent = estimateBattery();

        // Build and send JSON
        String json = buildJSON();

        if (connected) {
            sensorDataChar.writeValue(json);

            // Flash blue LED briefly to indicate transmission
            ledOn(LED_BLUE);
        }

        // Also output to Serial for debugging when connected via USB
        Serial.println(json);
    }

    // ── BLE Reset Command ──
    // Dashboard can write 0x01 to trigger a software reboot
    if (resetCmdChar.written()) {
        if (resetCmdChar.value() == 1) {
            Serial.println(F("BLE reset command received — rebooting..."));
            delay(100);  // let BLE response flush
            NVIC_SystemReset();
        }
    }

    // ── LED Management ──
    if (now - lastLEDUpdate >= LED_INTERVAL) {
        lastLEDUpdate = now;

        // Green: BLE connected
        if (connected) {
            ledOn(LED_GREEN);
        } else {
            // Blink green while advertising
            static bool greenState = false;
            greenState = !greenState;
            if (greenState) ledOn(LED_GREEN);
            else ledOff(LED_GREEN);
        }

        // Turn off blue LED after brief flash (it was turned on during transmit)
        ledOff(LED_BLUE);

        // Red: sensor error
        if (!max30102_ok || !imu_ok) {
            ledOn(LED_RED);
        } else {
            ledOff(LED_RED);
        }
    }

    // ── Software Watchdog ──
    // If the loop takes more than 5 seconds, something is hung — reset
    if (millis() - loopStartTime > WATCHDOG_TIMEOUT) {
        Serial.println(F("WATCHDOG: Loop stall detected — resetting"));
        NVIC_SystemReset();
    }

    // ── I2C Bus Recovery ──
    // If we accumulate too many I2C errors, reset the bus
    // (i2cErrorCount is incremented in sensor read functions if they detect errors)
    if (i2cErrorCount >= I2C_ERROR_THRESHOLD) {
        Serial.println(F("I2C: Too many errors — recovering bus"));
        recoverI2C();

        // Re-initialize MAX30102 after bus recovery
        if (max30102_ok) {
            if (!particleSensor.begin(Wire, I2C_SPEED_FAST)) {
                max30102_ok = false;
                Serial.println(F("MAX30102: Failed to re-initialize after I2C recovery"));
            } else {
                particleSensor.setup(0x1F, 4, 2, 400, 411, 4096);
            }
        }
    }
}

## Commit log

2026-03-22 Initial commit: NeuraFy wearable biomarker monitor
    Complete science fair project for Alzheimer's disease early detection:
    - Firmware: Arduino Nano 33 BLE Sense Rev2 with MAX30102 (HR/SpO2),
    Grove GSR (skin conductance), BMI270 IMU (gait analysis), BLE streaming
    - Dashboard: Chrome Web Bluetooth clinical interface with real-time charts,
    HRV analysis, clinical decision support, dark/light mode, CSV export
    - Enclosure: OpenSCAD pill-shaped case (70x42x18mm) with Apple Watch band
    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
    [bottom_shell.stl, neuraband_case.scad, print_bottom_shell.scad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]
2026-03-22 Add comprehensive project README
    Complete documentation covering system architecture, features,
    quick start guide, BOM, BLE protocol, and scientific context
    for the NeuraFy wearable biomarker monitor.
2026-03-24 Clinical dashboard redesign + 10-modality firmware upgrade
    - Dashboard: clinical-grade layout with 4-column vitals, session stats
    bar, dual-axis charts (HR+SpO2, GSR+Gait), trend arrows, collapsible
    data log, ARIA accessibility, 4-tier responsive breakpoints
    - Firmware: added respiratory rate (PPG envelope), skin temperature
    (HS3003), sleep actigraphy (BMI270), humidity (HS3003), ambient light
    (APDS9960), barometric pressure (LPS22HB), composite neuro-risk index
    - 10 biomarker modalities streaming at 1Hz over BLE
    - Clinical decision support with 21 evidence-based insight rules
    - Dark/light theme, CSV export, auto-reconnect, session timer
    [neuraband_firmware.ino]
2026-03-27 Updated dashboard + Band enclosure
    [arduino.stl, battery.stl, bottom_shell.stl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]
2026-04-07 Add detailed parts list PDF with Amazon links + updated renders
    - Created comprehensive BOM PDF (docs/NeuraFy_Parts_List.pdf) with exact
    product names, specifications, prices, and purchase links for all 19 parts
    - Added PDF generator script (docs/generate_bom_pdf.py) for regeneration
    - Updated Blender render script and all 8 render images (hero, exploded,
    bottom skin, USB port, internals, closeup top, hero bokeh, USB side)
2026-04-10 Add mobile app launch instructions to README
    The README documented firmware and dashboard setup but was missing a
    section for the Expo mobile app. Added a step 4 covering npm install,
    expo start, and the device requirements so the mobile app is runnable
    from a fresh clone without guessing.
2026-05-15 Redesign README with device renders and corrected specs; add LICENSE
    - Embed enclosure renders and a live dashboard screenshot
    - Document all 10 sensor modalities, the mobile app, and the BLE JSON frame
    - Correct the firmware line count and align the BOM with docs/bom.md
    - Add the MIT LICENSE file referenced by the README
